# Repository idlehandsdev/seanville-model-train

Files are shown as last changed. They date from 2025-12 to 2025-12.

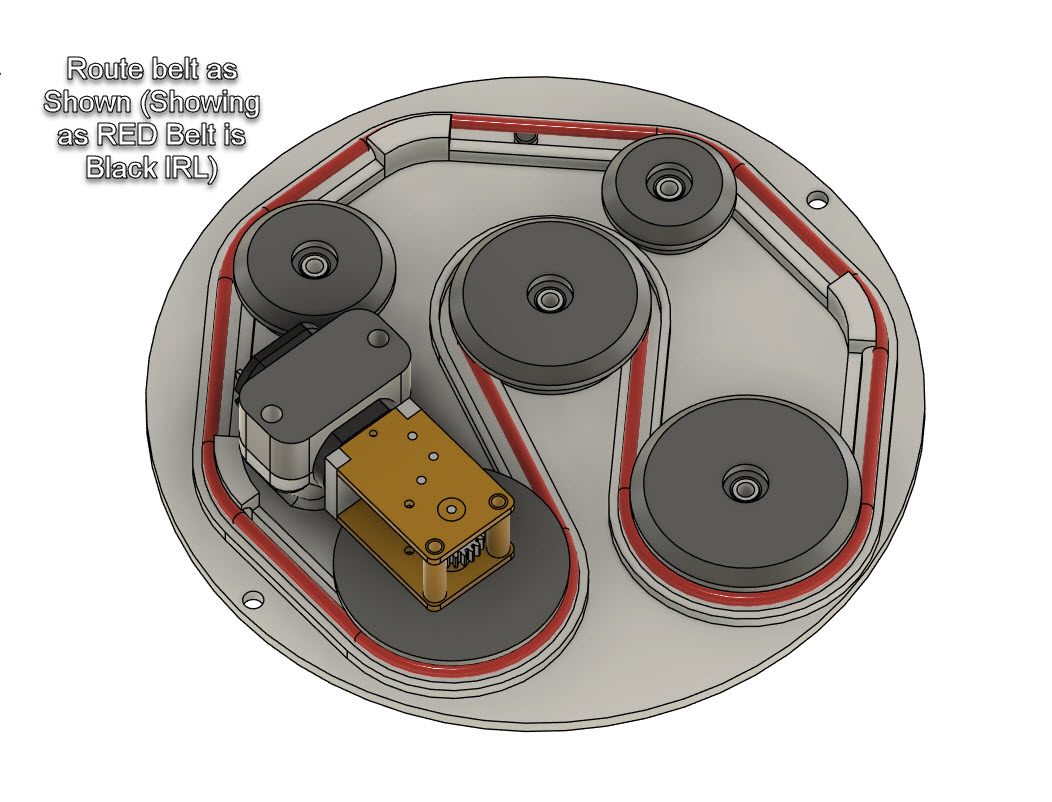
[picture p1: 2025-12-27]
instructables/belt_route.jpg

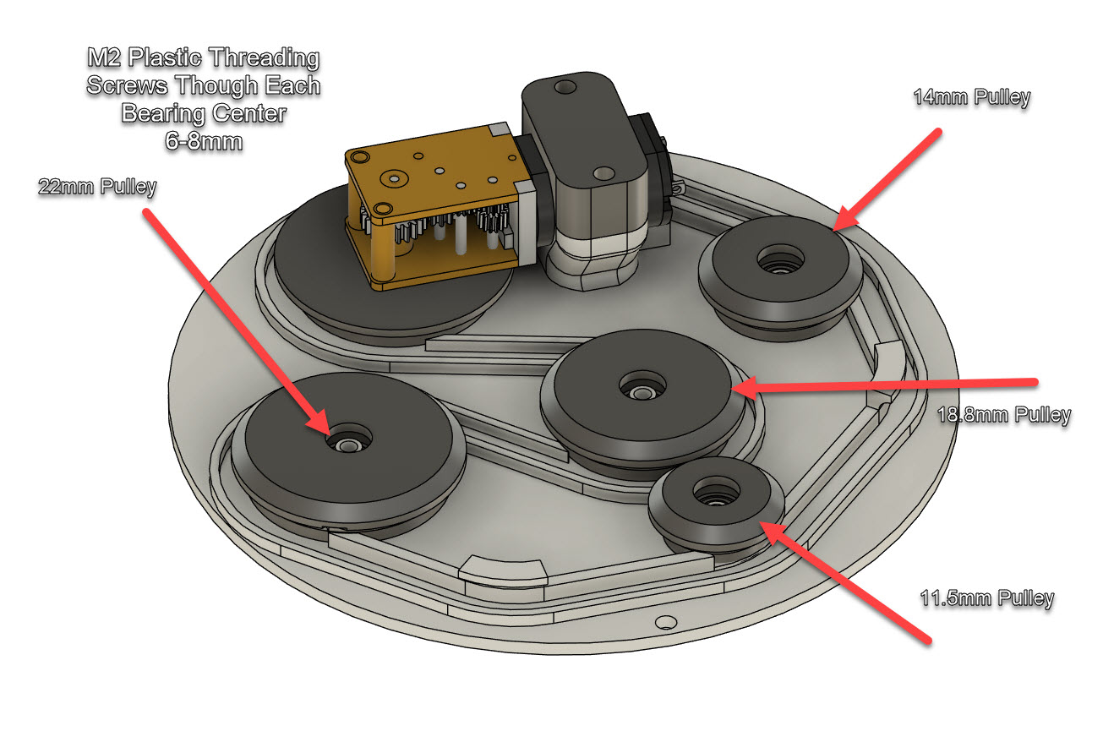
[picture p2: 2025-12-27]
instructables/pulley_screws.jpg

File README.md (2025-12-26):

# SeanVille Model Train Christmas Ornament (2025)

Watch the video (https://youtu.be/DlL3AunnM_I?si=Leu87hB8kkKHowt8)

This is my **2025 Christmas ornament project**.  
A fully self-contained **tiny model train and diorama** designed to fit entirely inside a clear Christmas ornament.

For the full context, design journey, and why some things changed along the way, **watch the video above**.

---

## Overview

The goal of this project was to build a miniature train system that could live inside a Christmas ornament while still feeling like a complete, moving system.

The original concept explored an electronically driven track, using timed control to advance the train around a PCB. As development progressed and real-world constraints showed up, the design pivoted to a **mechanically driven solution** that was simpler, more reliable, and better suited to the timeline.

The current version uses a **tiny mechanical belt system** that moves a magnet beneath the board.  
As the magnet advances, the train follows along the track above.

---

## 🚧 Work in Progress

This project is **still a work in progress**.

- The tiny magnetic track system needs further development
- Motion is currently limited and likely needs more voltage
- Additional tuning is required for smoother and more consistent movement

All of this is discussed in the video, including why the pivot happened and what still needs improvement.

---

## Current Design

- Mechanical belt-driven magnet system
- Train follows the magnet around a fixed loop
- Ornament-sized, self-contained footprint
- Designed for continuous motion and display
- Built with iteration and modularity in mind

Future revisions may revisit electronically driven concepts once reliability and timing constraints are better understood.

---

## Hardware and Parts

- **Controller:** Adafruit ESP32 Feather V2  
- **Lighting:** Adafruit wireless LED coil for flexible, wire-free lighting placement  
- **Mechanical components:** Belts, magnets, bearings, and fasteners sourced from McMaster-Carr  
- **Structure:** Custom 3D printed parts for alignment, mounting, and enclosure  

The project combines off-the-shelf hardware with printed components to keep it accessible while maintaining precision.

---

## Repository Contents

This repository contains design files, firmware, and assets related to the project.

You are encouraged to:
- Modify the design
- Improve the mechanics
- Adapt it for your own ornament, diorama, or tiny controlled environment

If you build one, or make it do something unexpected, I’d love to see it.

---

## Final Notes

Like most engineering projects, this one is shaped by compromise, iteration, and time.

What ships is never the first idea.  
It’s the version that survives.

It’s small.  
It loops.  
It runs quietly in the background.

Which feels appropriate.

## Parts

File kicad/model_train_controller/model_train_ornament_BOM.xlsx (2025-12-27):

 |  |  | xxxx xxxx xxxxx xxPCS BOM (Sample Bill of Materials)
Item # | *Designator | *Qty | Manufacturer | *Mfg Part # | Description / Value | *Package/Footprint | Type | Your Instructions / Notes
1 | A1 | 1 | Adafruit Feather ESP32 V2 |  |  |  | DNP | Feather Headers
2 | D1,D2,D3,D6 | 4 | Diodes Incorporated | 1N4148W-7-F | DIODE STANDARD 100V 150MA SOD123 | SOD-123 | SMD
3 | D4 | 1 | onsemi | MBR230LSFT1G | DIODE SCHOTTKY 30V 2A SOD123FL | SOD-123F | SMD
4 | F1,F2,F3 | 3 | Bourns Inc. | MF-USML300/6-2 | PTC RESET FUSE 6V 3A 1210 | 1210 (3225 Metric) | SMD
5 | J1 | 1 | Würth Elektronik | 691210910004 | TERM BLOCK 4P HORIZON 2.54MM PCB | 4 Position Wire to Board Terminal Block | Through Hole
6 | J2,J6 | 2 | Phoenix Contact | 1751248 | TERM BLK 2POS SIDE ENT 3.5MM PCB | 2 Position Wire to Board Terminal Block | Through Hole
7 | J3 | 1 | Same Sky (Formerly CUI Devices) | PJ-063AH | CONN PWR JACK 2X5.5MM SOLDER | Power Barrel Connector Jack 2.10mm ID (0.083"), 5.50mm OD (0.217") | Through Hole
8 | J5 | 1 | Phoenix Contact | 1725698 | TERM BLK 6P SIDE ENT 2.54MM PCB | 6 Position Wire to Board Terminal Block | DNP | Refer to Image for Populating(leave for customer)
9 | JP1 | 1 | Molex | 22285034 | CONN HEADER VERT 3POS 2.54MM | Connector Header Through Hole 3 position 0.100" | Through Hole
10 | Q1,Q2,Q3,Q5 | 4 | Alpha & Omega Semiconductor Inc. | AOSP36326C | MOSFET N-CH 30V 12A 8SOIC | 8-SOIC | SMD
11 | R1,R2,R3,R7 | 4 | YAGEO | AC0805FR-07220RL | 220 Ohms ±1% 0.125W, 1/8W Chip Resistor 0805 (2012 Metric) | 0805 (2012 Metric) | SMD
12 | R4,R5,R6,R8 | 4 | YAGEO | RC0805FR-0710KL | 10 kOhms ±1% 0.125W, 1/8W Chip Resistor | 0805 (2012 Metric) | SMD
Need a quick and accurante quote? Need an efficient production? Please read SMT Ordering Necessary Files & Info in 1 minute. Thank you very much!
Click for Instructions on How to Create a BOM (https://www.pcbway.com/blog/PCB_Assembly/How_to_Build_a_BOM__Bill_Of_Materials_.html)

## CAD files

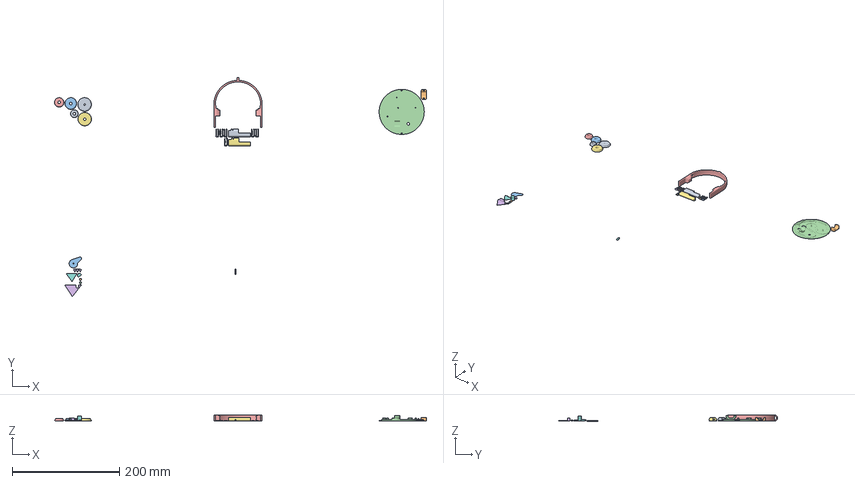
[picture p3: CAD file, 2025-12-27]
CAD/SeanVille_Model_Train_Full.3mf
692.5 x 408.0 x 12.0 mm
drive_pulley.stl
motor_clamp.stl
Lake.stl
belt_track_bearings
LED Hoop and Leg.stl
Tree Three.stl
idler_pulley_right_8mm_22.stl
Workshop.stl
Leg.stl x 2
House Big.stl
idler_pulley_center_8mm_18.stl
House Small.stl
idler_pulley_center_8mm_14.stl
Mountain_rear
Mountain_front
idler_pulley_center_8mm_11.stl
LED Clip.stl x 6
train_engine_diesel.stl

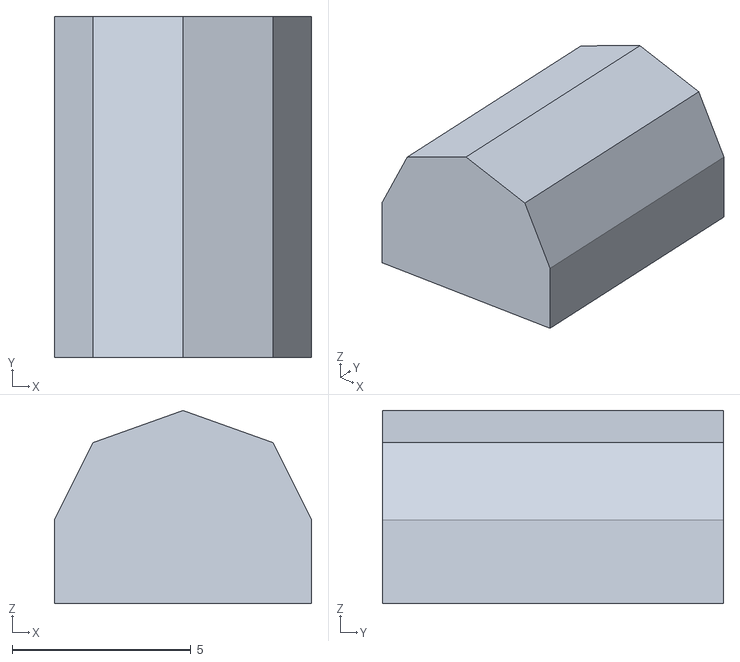
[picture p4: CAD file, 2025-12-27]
CAD/STLs/Workshop.stl
7.20 x 9.54 x 5.40

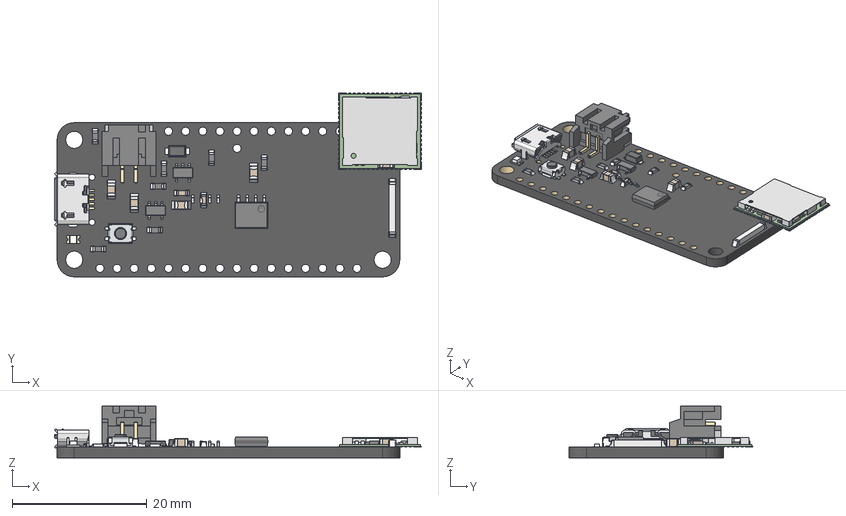
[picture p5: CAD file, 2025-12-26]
kicad/model_train_controller/project_libs/3DPackages/WICED Feather v26 v1.step
54.4 x 27.2 x 7.64 mm
board
P0
P0 solder
pin x 2
mount x 2
housing
TSOP-5 v3 x 2
cap0805_05 v2 x 5
cap0805_03 v2
cap0603_03 v3 x 2
smt_tact_button v3
package
lead x 4
lead (mirror) x 4
resistor_0603 v2 x 7
smt_led_0805 v2 x 2
SOD123W v2

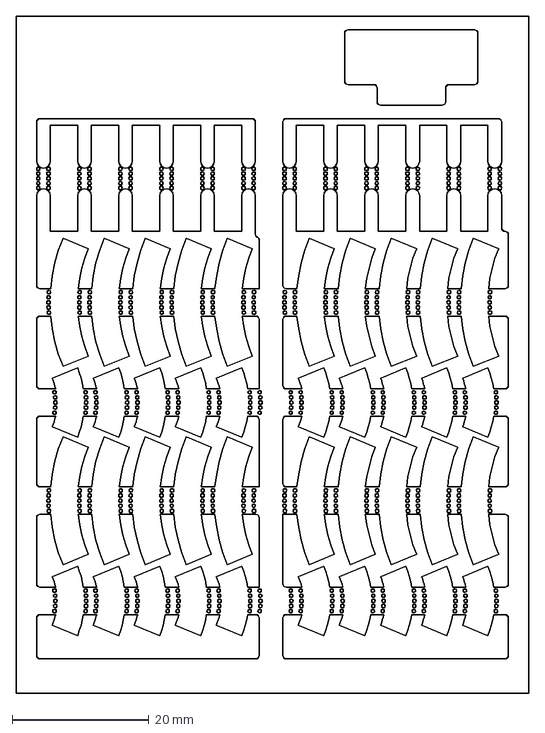
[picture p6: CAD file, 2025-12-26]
kicad/model_train_ornament/model_train_tracks_fixed.dxf
75.0 x 99.0 mm

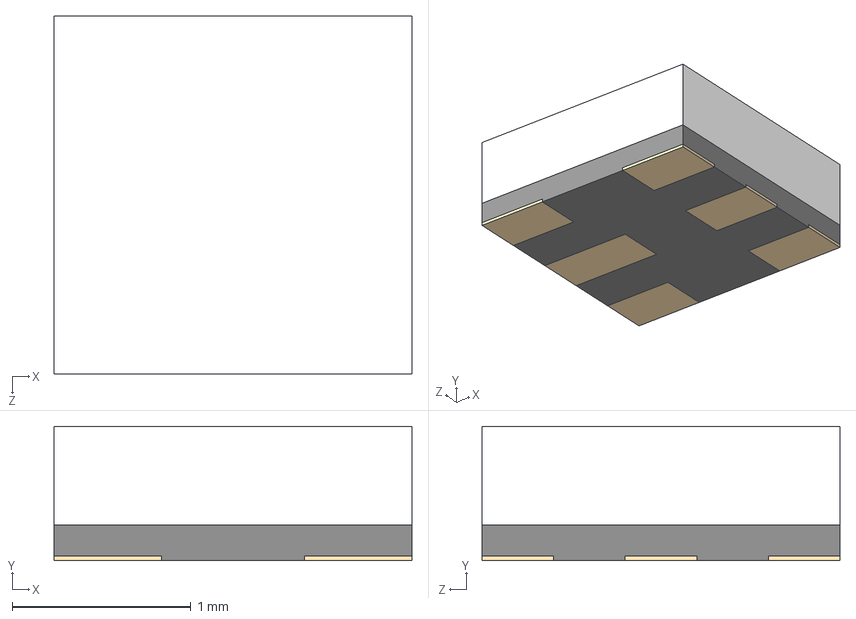
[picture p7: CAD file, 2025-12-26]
kicad/model_train_ornament/project_libs/3DPackages/BB-2020BGR-TRB.step
2.00 x 0.75 x 2.00 mm

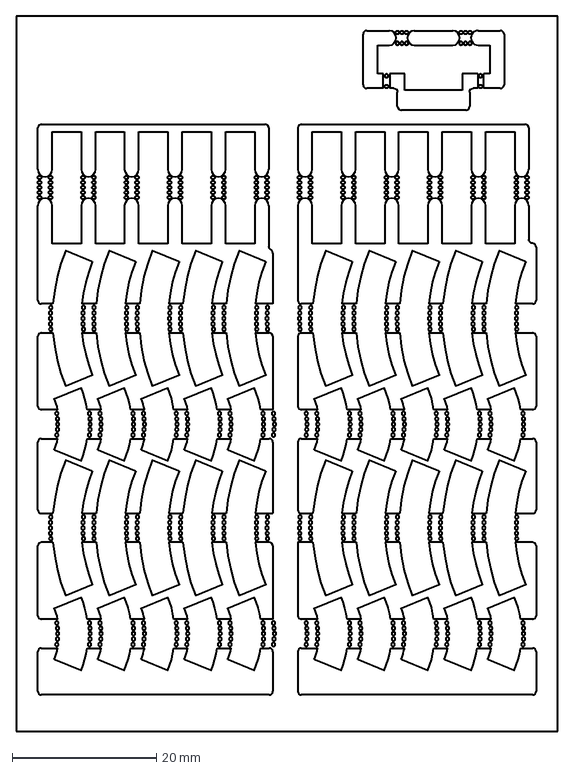
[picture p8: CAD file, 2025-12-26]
kicad/model_train_template/model_train_tracks_power.dxf
75.0 x 99.0 mm

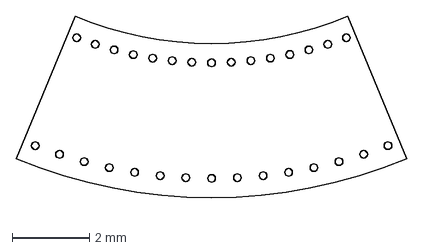
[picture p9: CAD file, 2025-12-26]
kicad/track_left_30/track_right_30_fixed.dxf
10.1 x 5.04 mm

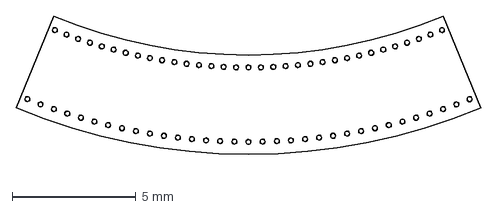
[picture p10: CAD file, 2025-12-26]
kicad/track_left_45/track_right_45.dxf
18.8 x 6.18 mm

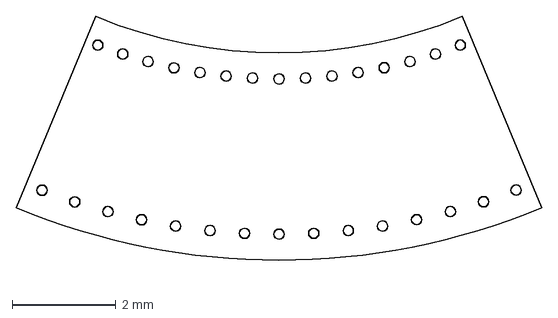
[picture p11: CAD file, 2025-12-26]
kicad/track_right_30/track_right_30.dxf
10.1 x 5.04 mm

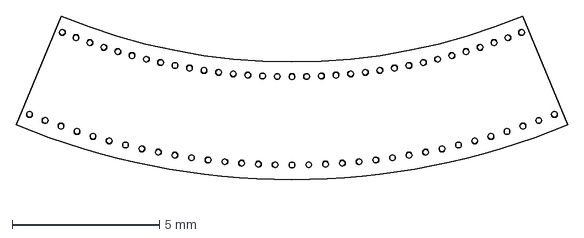
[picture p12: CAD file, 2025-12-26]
kicad/track_right_45/track_right_45_fixed.dxf
18.8 x 6.18 mm

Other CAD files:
CAD/Mountain_front.3mf
CAD/Mountain_rear.3mf
CAD/STLs/House Big.stl
CAD/STLs/House Small.stl
CAD/STLs/LED Clip.stl
CAD/STLs/LED Hoop and Leg.stl
CAD/STLs/Lake.stl
CAD/STLs/Leg.stl
CAD/STLs/Mountain Front.stl
CAD/STLs/Mountain Rear.stl
CAD/STLs/Track Base Belt Guide.stl
CAD/STLs/Tree Three.stl
CAD/STLs/drive_pulley.stl
CAD/STLs/idler_pulley_center_8mm_11.stl
CAD/STLs/idler_pulley_center_8mm_14.stl
CAD/STLs/idler_pulley_center_8mm_18.stl
CAD/STLs/idler_pulley_right_8mm_22.stl
CAD/STLs/motor_clamp.stl
CAD/STLs/train_engine_diesel.stl
CAD/belt_track_bearings.3mf
CAD/pcbway_building.3mf
kicad/model_train_ornament/model_train_ornament.step
kicad/model_train_ornament/model_train_tracks.dxf
kicad/model_train_ornament/model_train_tracks_fixed_2.dxf
kicad/model_train_single_sheet/model_train_tracks.dxf
kicad/model_train_single_sheet/model_train_tracks_fixed_2.dxf
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

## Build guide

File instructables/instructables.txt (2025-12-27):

Instructables

Parts
1 x Neodymium Magnet 1/16" Thick, 0.1" OD - https://www.mcmaster.com/5862K426/ 
1 x Neodymium Magnet 1/16" Thick, 1/16" OD - https://www.mcmaster.com/5862K137/  (get a bunch theyre small)
M2 x 10mm Plastic Threading Screws
M2 x 8mm Plastic Threading Screws
3x8x4mm Bearings x 4
1.5mm Belt ~ 10.75 length"
Adafruit Wireless LED Kit
Adafruit Feather ESP32 V2
Dotstar LED Strip (A couple Inches)
Tiny 0.6-0.8 wire (I used leads from a Capacitor)
Right Angle Geared DC Motor
Cut Dotstar LED Strip (16 LEDs)
Circuit Board from PCB - link to project

Electrical Component BOM(refer to schematics)
		
1N4148W Diotec Semiconductor x 4	
MBR230LSFT1G  x 1	
MF-USML300/12-2 x 4	
6 Pin 2.54mm Screw Terminal 1725698 Phoenix Contact x 1	
2 Pin 3.5mm Screw Terminal 1751248 Phoenix Contact x 2
4 Pin 2.54mm Screw Terminal x 1	
PJ-063AH x 1	
AOSP36326C x 4	
220R Resistor 0805 x 4
10K Resistor 0805 x 4
01x16 Pin Socket x 1
01x12 x 1

Parts to Print
Some parts require a 0.2mm nozzle

Leg LED Ring x 1
Legs x 2
Track Base Belt Guide x 1
Motor Clamp Half x 1
Idler Pulley 11mm x 1
Idler Pulley 14mm x 1
Idler Pulley 18.8mm x 1
Idler Pulley 22mm x 1
Drive Pulley x 1
LED_Clip x 6

Optional Parts to Print(as needed)
Workshop
Trees_Three
House_Big
House_Small
Lake
Mountain

Fusion360 File Viewer - https://a360.co/49g66Fe
Instructables - https://www.instructables.com/Extremely-Tiny-Model-Train-Christmas-Ornament/
PCBWay PCB Project - https://www.pcbway.com/project/shareproject/SeanVille_Tiny_Model_Train_Christmas_Ornament_Controller_4a13288b.html

Instructables Steps:

-) Watch the Video
-) Get the parts
-) Start the 3d prints, you'll be printing a lot of small stuff
-) Apply paste to PCB
-) Add small components and Reflow
-) Solder Through Hole Components - Use the Fusion360 CAD file for reference
-) Push the bearings into the 4 pulleys, and mount the pulleys on the Track Base Belt Guide Screw them down with M2 plastic threading screws
-) Push the drive pulley onto the DC Motor, add the motor clamp to hold it down, you need to align the center of the shaft with the center of the Track Base Belt Guide, align and tighten down
-) Route the Belt around the drive and idlers
-)Print Engine and Install Magnet and Wire
-) Insert the larger of the two neodymium magnets into the track and under the belt, the magnet moves by friction from the belt moving overtop of it.
-) Use doublesided tape to secure the LED strip to the underside of the hoop, apple the 3D printed clips to help the adhesive, route the LED strip wires through the hole.
-) Attach the completed circuit board to the bottom of the hoop connections, attach the legs to the circuit board as well, before installing the final leg, insert the wireless LED coil. The legs and slot will hold it in place. Connect the wires to the control board.

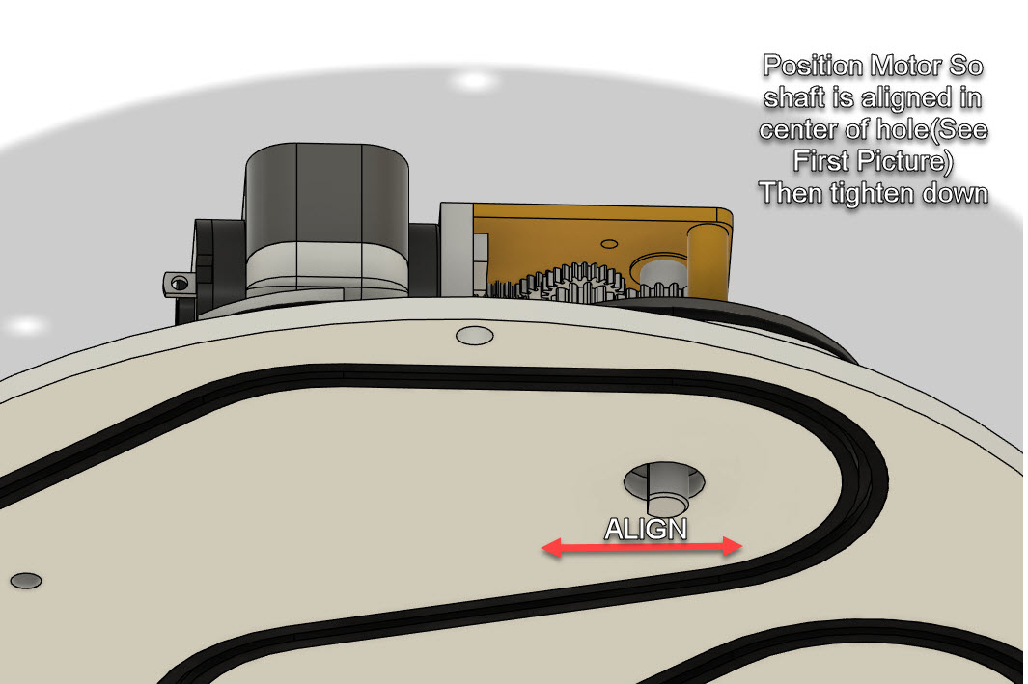
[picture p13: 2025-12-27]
instructables/motor_align.jpg

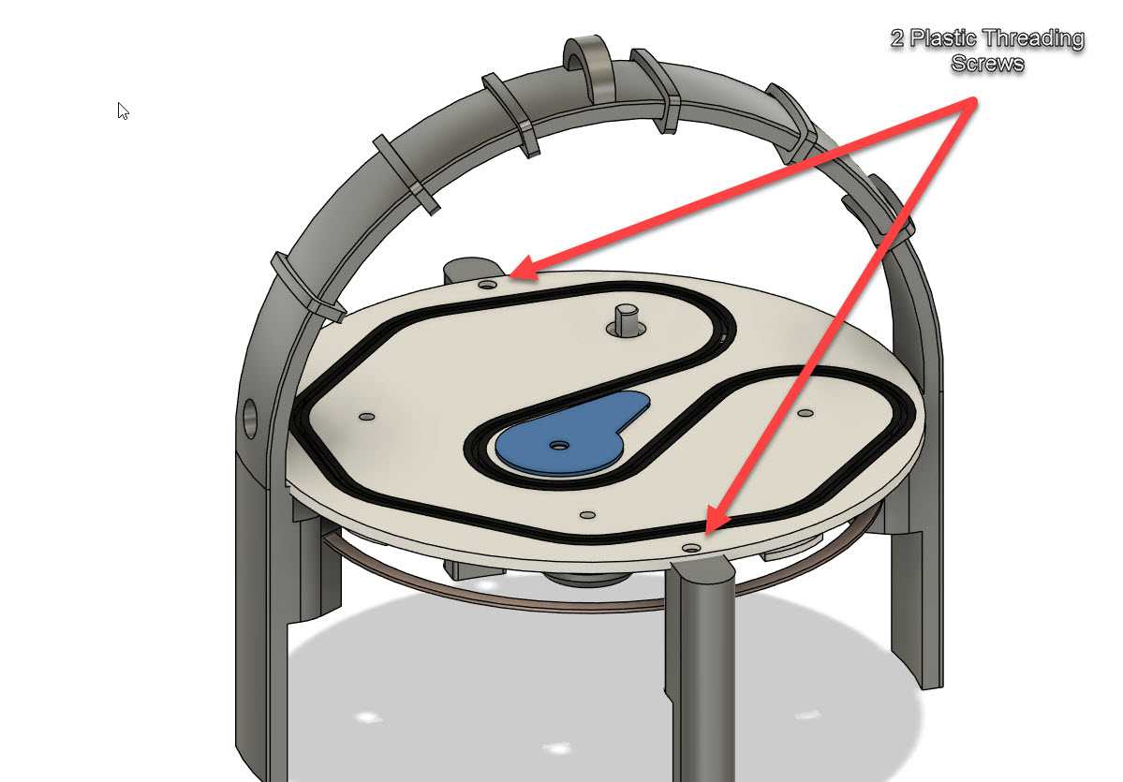
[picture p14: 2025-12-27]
instructables/base_mount.jpg

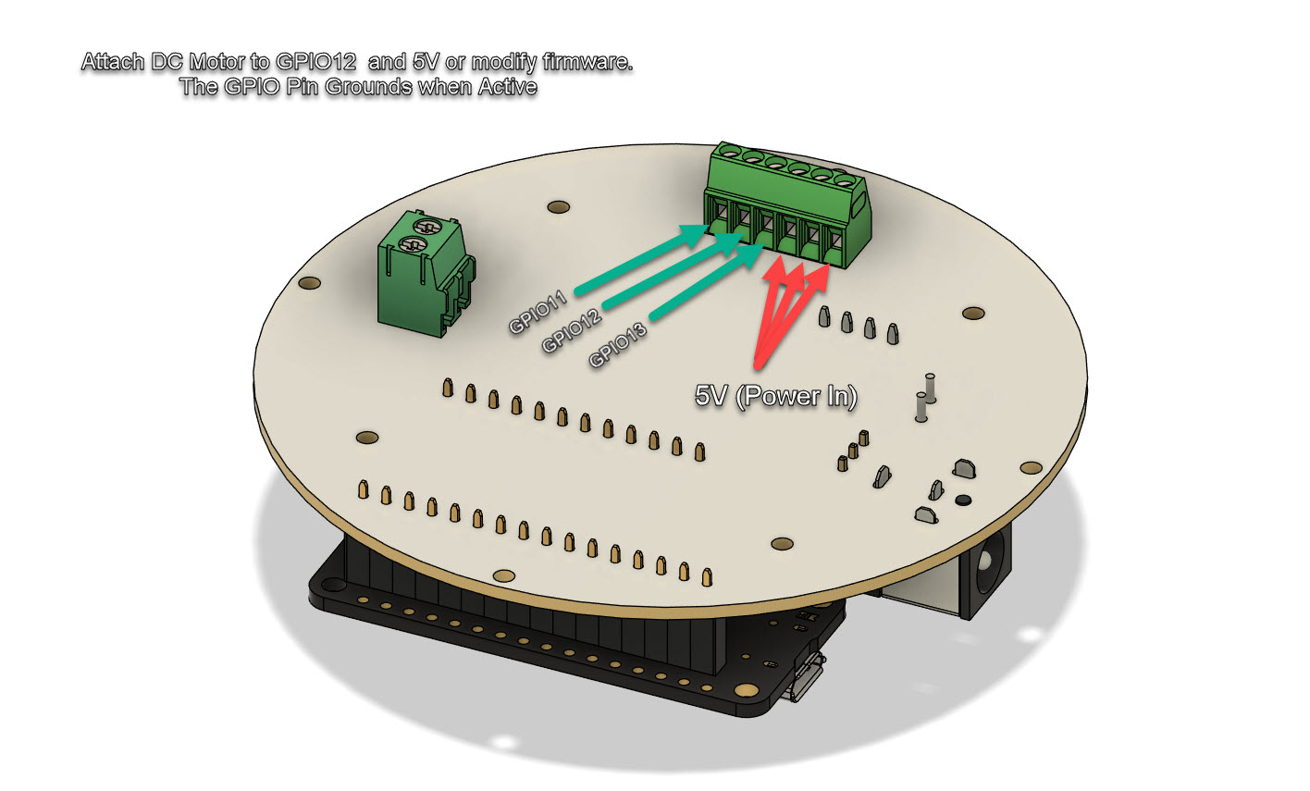
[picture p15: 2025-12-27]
instructables/motor_connection.jpg

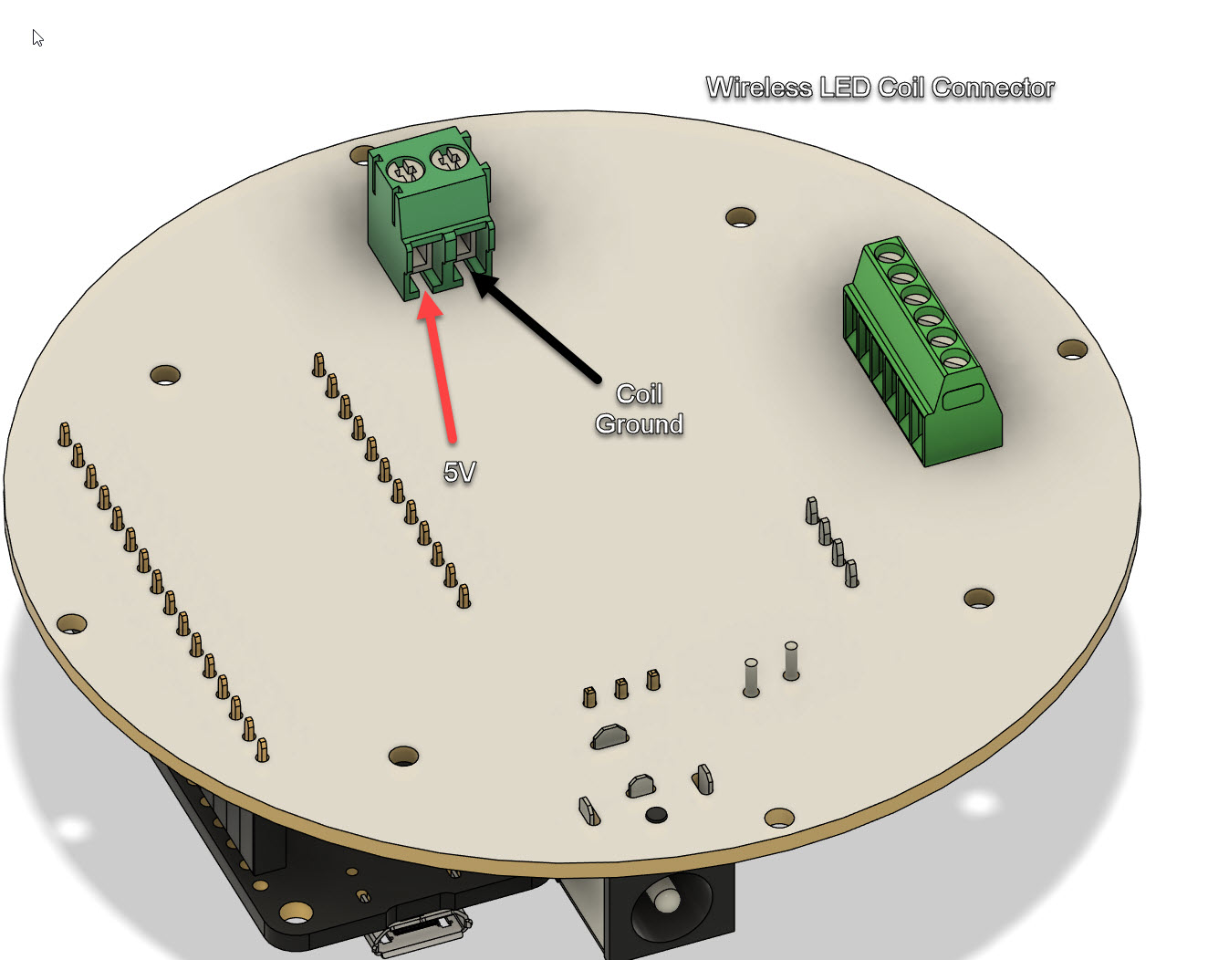
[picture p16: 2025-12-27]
instructables/wireless_coil_connections.jpg

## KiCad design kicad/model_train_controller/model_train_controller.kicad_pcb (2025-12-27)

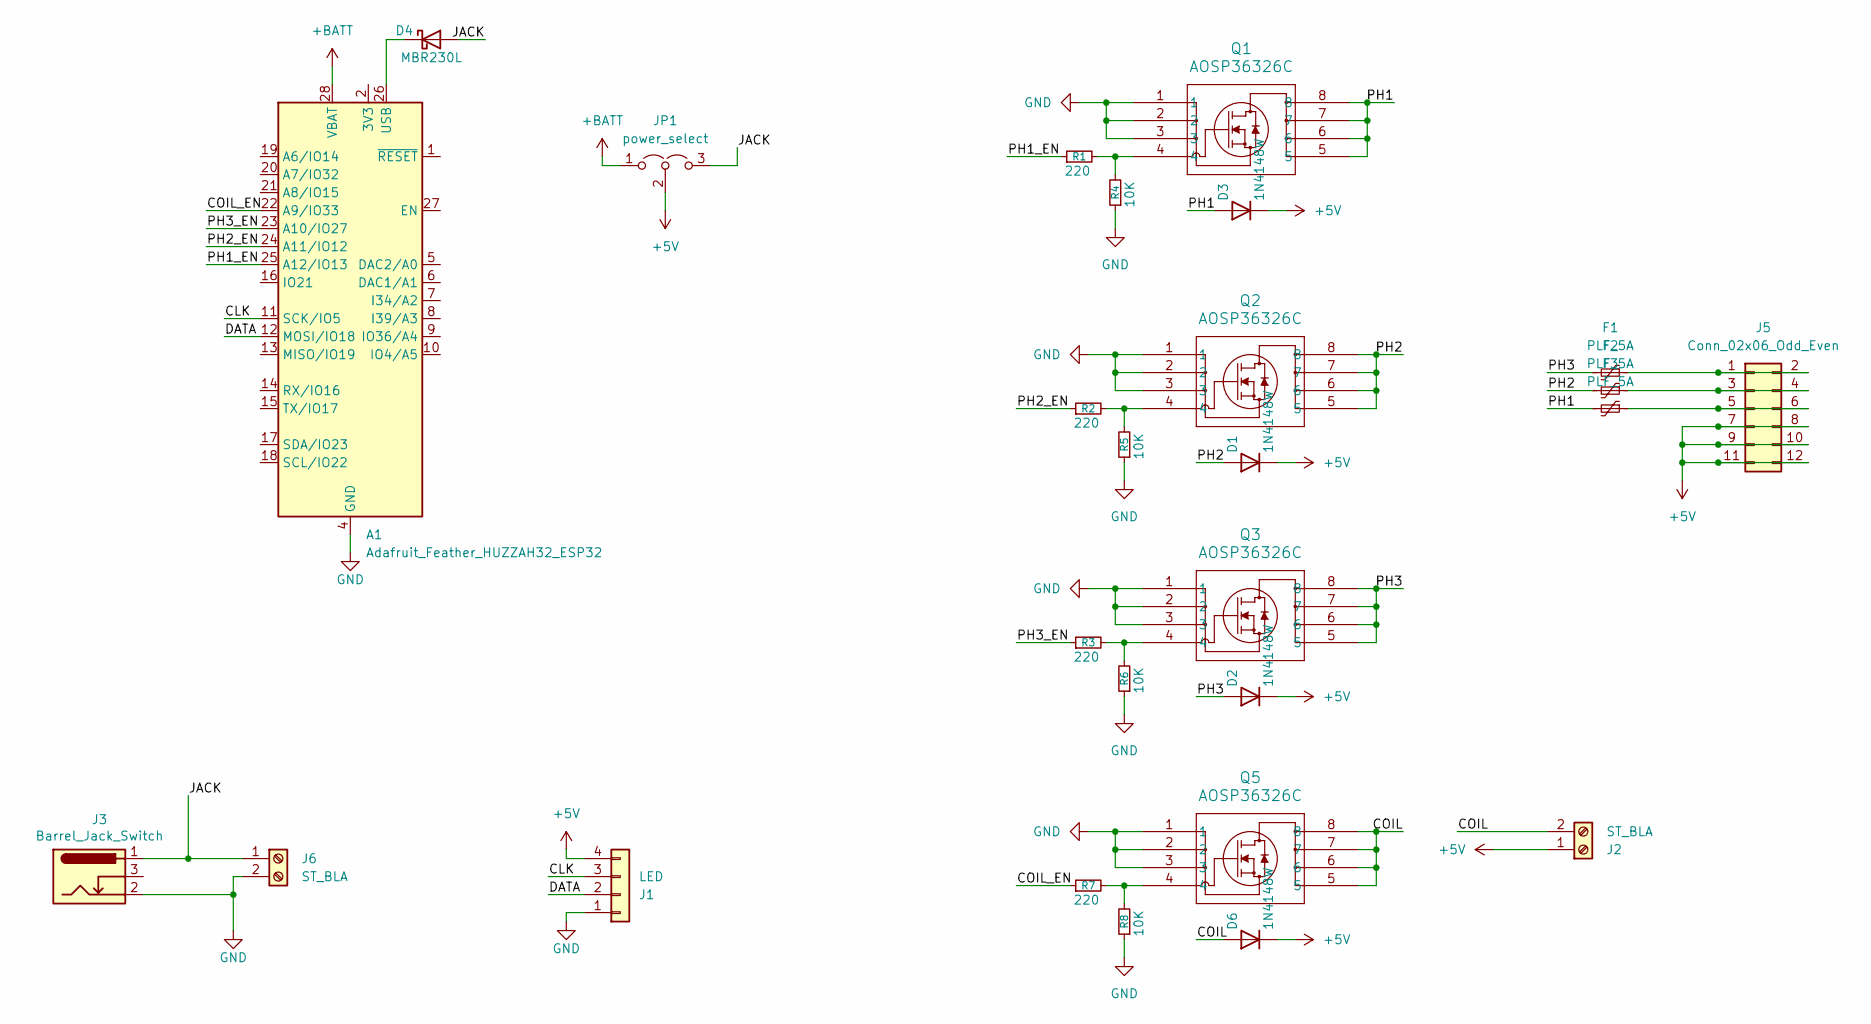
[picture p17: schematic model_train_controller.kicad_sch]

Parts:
A1: Adafruit_Feather_HUZZAH32_ESP32; Adafruit_Feather; Digikey Part No. 1528-5477-ND
D1, D2, D3, D6: 1N4148W; D_SOD-123; Digikey Part No. 1N4148W-FDITR-ND
D4: MBR230L; D_SOD-123F; Digikey Part No. MBR230LSFT1GOSCT-ND
F1, F2, F3: PLF_5A; Fuse_1210_3225Metric; Digikey Part No. 118-MF-USML300/6-2CT-ND
J1: LED; TerminalBlock_Phoenix_MPT-0,5-4-2.54_1x04_P2.54mm_Horizontal; Digikey Part No. 732-691210910004-ND
J2, J6: ST_BLA; TerminalBlock_Phoenix_PT-1,5-2-3.5-H_1x02_P3.50mm_Horizontal; Digikey Part No. 277-5719-ND
J3: Barrel_Jack_Switch; BarrelJack_CUI_PJ-063AH_Horizontal; Digikey Part No. CP-063AH-ND
J5: Conn_02x06_Odd_Even; PinHeader_2x06_P2.54mm_Vertical; Digikey Part No. 2057-PH2-12-UA-ND
JP1: power_select; PinHeader_1x03_P2.54mm_Vertical
Q1, Q2, Q3, Q5: AOSP36326C; SO8SOP-8L_AOS; Digikey Part No. 785-AOSP36326CCT-ND
R1, R2, R3, R7: 220; R_0805_2012Metric; Digikey Part No. YAG3711CT-ND
R4, R5, R6, R8: 10K; R_0805_2012Metric; Digikey Part No. 311-10.0KCRTR-ND

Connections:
+5V: D1.1 (K), D2.1 (K), D3.1 (K), D6.1 (K), J1.4, J2.1, J5.7, J5.8, J5.9, J5.10, J5.11, J5.12, JP1.2 (C)
+BATT: A1.28 (VBAT), JP1.1 (A)
/CLK: A1.11 (SCK/IO5), J1.3
/COIL: D6.2 (A), J2.2, Q5.5, Q5.6, Q5.7, Q5.8
/COIL_EN: A1.22 (A9/IO33), R7.1
/DATA: A1.12 (MOSI/IO18), J1.2
/JACK: D4.2 (A), J3.1, J6.1, JP1.3 (B)
/PH1: D3.2 (A), F3.2, Q1.5, Q1.6, Q1.7, Q1.8
/PH1_EN: A1.25 (A12/IO13), R1.1
/PH2: D1.2 (A), F2.2, Q2.5, Q2.6, Q2.7, Q2.8
/PH2_EN: A1.24 (A11/IO12), R2.1
/PH3: D2.2 (A), F1.2, Q3.5, Q3.6, Q3.7, Q3.8
/PH3_EN: A1.23 (A10/IO27), R3.1
GND: A1.4 (GND), J1.1, J3.2, J6.2, Q1.1, Q1.2, Q1.3, Q2.1, Q2.2, Q2.3, Q3.1, Q3.2, Q3.3, Q5.1, Q5.2, Q5.3, R4.1, R5.1, R6.1, R8.1
unnamed: A1.26 (USB), D4.1 (K)
unnamed: F1.1, J5.1, J5.2
unnamed: F2.1, J5.3, J5.4
unnamed: F3.1, J5.5, J5.6
unnamed: Q1.4, R1.2, R4.2
unnamed: Q2.4, R2.2, R5.2
unnamed: Q3.4, R3.2, R6.2
unnamed: Q5.4, R7.2, R8.2

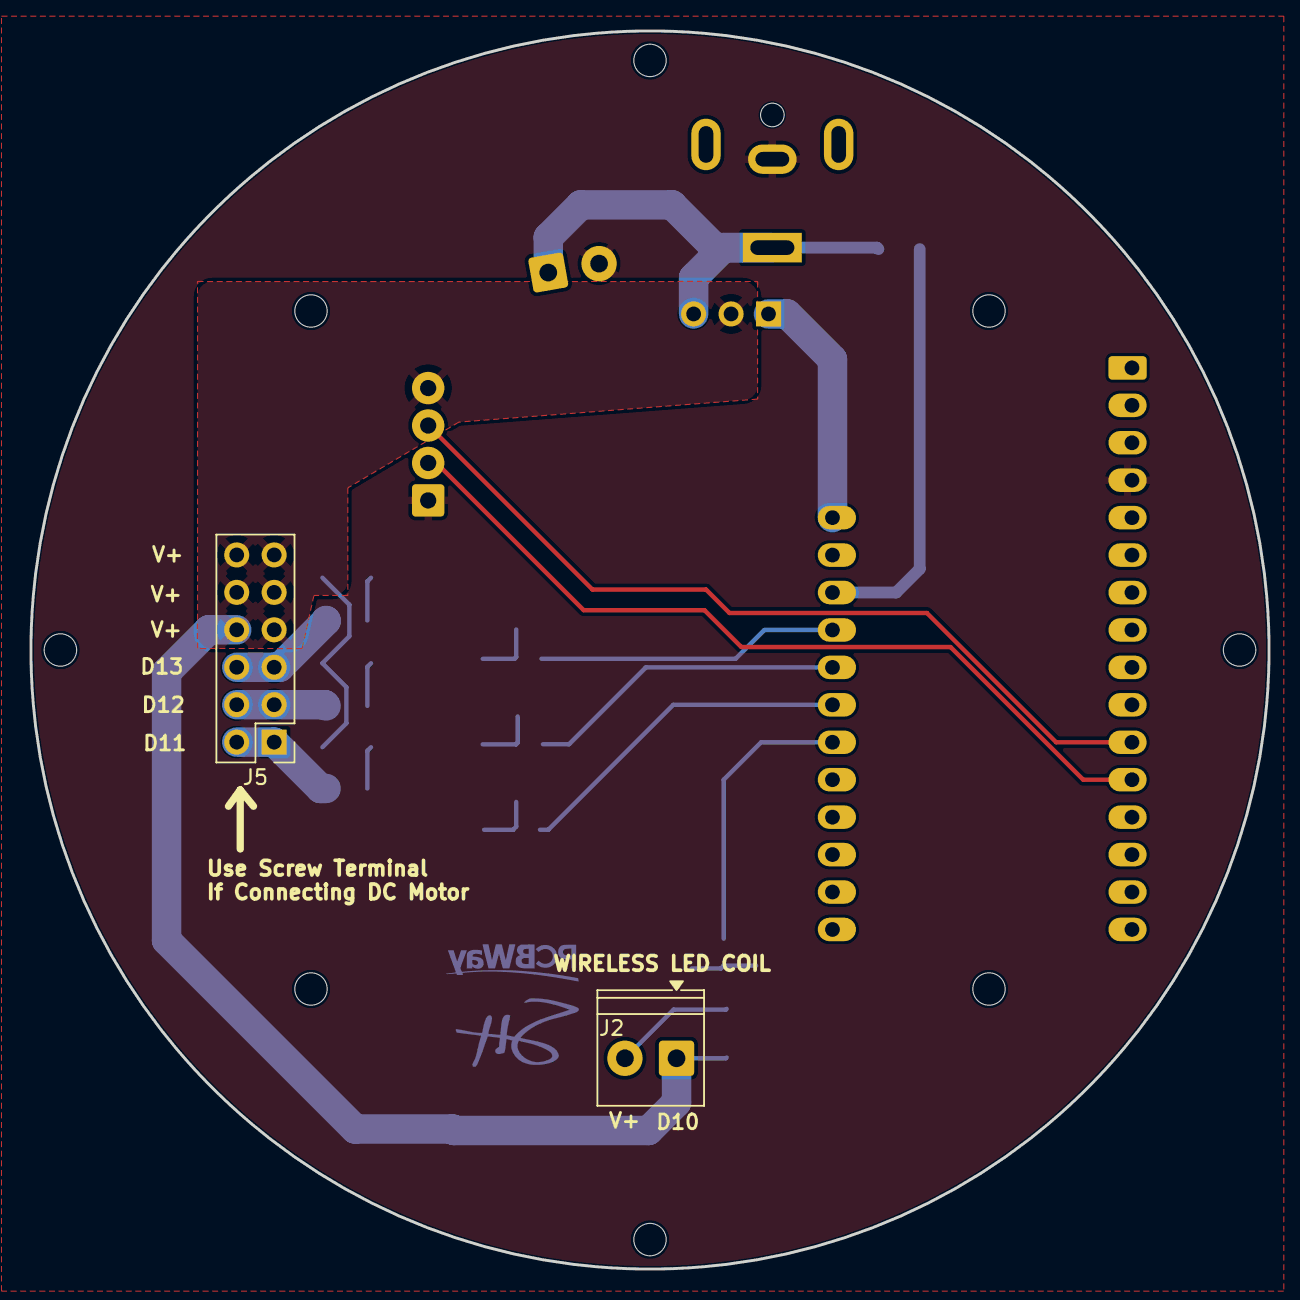
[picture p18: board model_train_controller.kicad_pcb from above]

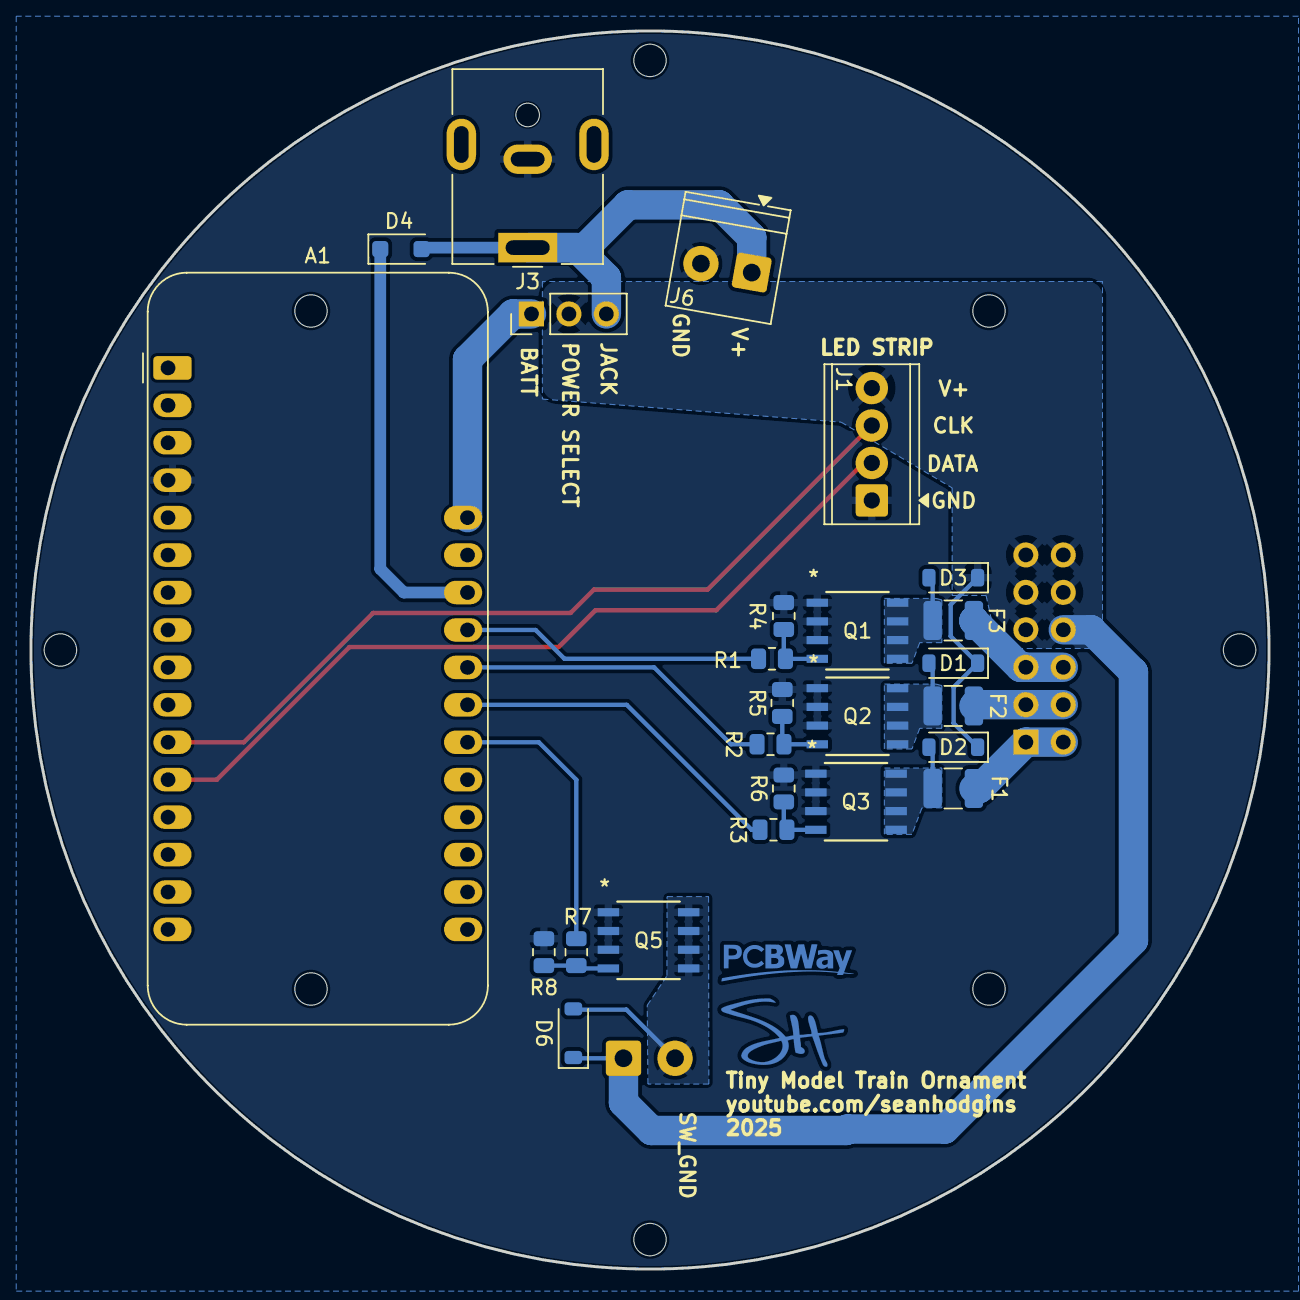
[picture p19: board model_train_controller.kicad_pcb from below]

Board: 2 copper layers, 84.0 x 84.0 mm, 27 parts (25 on the bottom side), 22 nets.

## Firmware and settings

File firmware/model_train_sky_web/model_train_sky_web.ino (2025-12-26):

/*
  ESP32-S3 Feather controller (based on your working sketch)

  Changes:
  - Added Sky Sim slider (seconds per simulated hour)
  - Added Sky Sim toggle button
  - Sky rendering is smooth between LEDs (blends two adjacent pixels)
  - Sun color shifts toward orange/red near ends (sunrise/sunset)
  - Sky is never intentionally cleared when train runs; periodic refresh keeps it "staying on"

  Pins:
  - Train DC motor: GPIO 12 (ON/OFF)
  - LED Ring: GPIO 10 (ON/OFF)
  - Sky: APA102 (16 LEDs) on MOSI/SCK
*/

#include <WiFi.h>
#include <WebServer.h>
#include <FastLED.h>
#include <time.h>

// -------- WiFi credentials --------
const char* WIFI_SSID = "YOUR_WIFI_SSID";
const char* WIFI_PASS = "YOUR_WIFI_PASSWORD";

// -------- Time / timezone --------
const char* TZ_INFO = "EST5EDT,M3.2.0/2,M11.1.0/2"; // America/Toronto rules
const char* NTP1 = "pool.ntp.org";
const char* NTP2 = "time.nist.gov";

// -------- Pins --------
static const uint8_t TRAIN_MOTOR_PIN = 12; // DC motor control (ON/OFF)
static const uint8_t LED_RING_PIN    = 10; // ON/OFF

// -------- APA102 Sky --------
static const uint8_t NUM_LEDS = 16;
CRGB leds[NUM_LEDS];

// Use Feather SPI pins (DATA=MOSI, CLK=SCK)
#ifndef MOSI
  #define MOSI 35
#endif
#ifndef SCK
  #define SCK 36
#endif
static const uint8_t APA_DATA_PIN = MOSI;
static const uint8_t APA_CLK_PIN  = SCK;

// -------- State --------
bool trainOn = false;
bool ringOn  = false;
bool skyOn   = true;

// Sky simulation
bool skySimOn = false;

// Slider controls this: real seconds per simulated hour
// (Integer slider -> float stored)
float simSecondsPerHour = 2.0f;

// Sim base time when sim is enabled
unsigned long simStartMs = 0;
int simStartHour = 12;
int simStartMinute = 0;

WebServer server(80);

// -------- Time helpers --------
bool getLocalTimeHM(int &hour24, int &minute) {
  struct tm timeinfo;
  if (!getLocalTime(&timeinfo, 50)) return false;
  hour24 = timeinfo.tm_hour;
  minute = timeinfo.tm_min;
  return true;
}

// Get sky time: real or simulated
bool getSkyTimeHM(int &hour24, int &minute) {
  if (!skySimOn) {
    // If real time temporarily fails, do not "turn off" sky; just keep last displayed
    return getLocalTimeHM(hour24, minute);
  }

  // simulated time: advance smoothly
  unsigned long now = millis();
  float elapsedSec = (now - simStartMs) / 1000.0f;

  // Guard against bad slider value
  float secPerHour = simSecondsPerHour;
  if (secPerHour < 1.0f) secPerHour = 1.0f;
  if (secPerHour > 60.0f) secPerHour = 60.0f;

  float simMinutesPerSecond = 60.0f / secPerHour;
  int deltaMinutes = (int)(elapsedSec * simMinutesPerSecond);

  int baseMinutes = simStartHour * 60 + simStartMinute;
  int totalMinutes = baseMinutes + deltaMinutes;

  totalMinutes %= (24 * 60);
  if (totalMinutes < 0) totalMinutes += (24 * 60);

  hour24 = totalMinutes / 60;
  minute = totalMinutes % 60;
  return true;
}

static inline float clamp01(float x) {
  if (x < 0.0f) return 0.0f;
  if (x > 1.0f) return 1.0f;
  return x;
}

static inline uint8_t toU8(float x) {
  if (x < 0.0f) x = 0.0f;
  if (x > 255.0f) x = 255.0f;
  return (uint8_t)(x + 0.5f);
}

// Sun color: yellow mid-day, more orange/red near ends
CRGB sunColorForT(float t01) {
  // t01 is 0..1 across day (sunrise->sunset)
  // "edge" is 1 at ends, 0 at middle
  float edge = fabsf(2.0f * t01 - 1.0f);  // 0 mid, 1 ends

  // Base "noon" color
  CRGB noon = CRGB(255, 200, 0);

  // Sunset/sunrise color (more orange/red)
  CRGB edgeCol = CRGB(255, 60, 0);

  // Blend factor: push stronger near edges
  float k = clamp01(edge * edge); // quadratic for nicer curve
  uint8_t kb = toU8(k * 255.0f);

  return blend(noon, edgeCol, kb);
}

// Moon color: bluish
CRGB moonColor() {
  return CRGB(0, 80, 255);
}

// Render sky smoothly between pixels (two adjacent LEDs blend)
void renderSkySmooth() {
  static int lastA = -999;
  static int lastB = -999;
  static uint8_t lastWa = 0;
  static uint8_t lastWb = 0;
  static bool lastIsDay = false;
  static unsigned long lastForceMs = 0;

  int h, m;
  if (!getSkyTimeHM(h, m)) {
    // If time isn't available, do nothing (do NOT clear)
    return;
  }

  const int dayStart = 6;
  const int dayEnd   = 18;
  bool isDay = (h >= dayStart && h < dayEnd);

  float hourFrac = (float)h + (float)m / 60.0f;

  // Compute t 0..1 across the active span (day or night)
  float t = 0.0f;
  if (isDay) {
    t = (hourFrac - dayStart) / (float)(dayEnd - dayStart);
  } else {
    float hf = hourFrac;
    if (hf < dayStart) hf += 24.0f; // wrap night segment
    t = (hf - dayEnd) / (float)((dayStart + 24) - dayEnd);
  }
  t = clamp01(t);

  // position in [0..NUM_LEDS-1], fractional
  float posf = t * (NUM_LEDS - 1);
  int a = (int)floorf(posf);
  int b = a + 1;
  if (b >= NUM_LEDS) b = NUM_LEDS - 1;

  float frac = posf - (float)a; // 0..1
  uint8_t wb = toU8(frac * 255.0f);
  uint8_t wa = 255 - wb;

  // Only redraw if something changed, but also force refresh periodically
  unsigned long now = millis();
  bool changed = (a != lastA) || (b != lastB) || (wa != lastWa) || (wb != lastWb) || (isDay != lastIsDay);
  bool force = (now - lastForceMs) > 2000; // force a show every 2s so it never "goes stale"

  if (!changed && !force) return;

  lastForceMs = now;
  lastA = a; lastB = b; lastWa = wa; lastWb = wb; lastIsDay = isDay;

  // Clear and set two pixels with brightness weights
  for (int i = 0; i < NUM_LEDS; i++) leds[i] = CRGB::Black;

  CRGB c = isDay ? sunColorForT(t) : moonColor();

  // Scale by weights (CRGB::nscale8_video keeps a minimum visible glow)
  CRGB ca = c; ca.nscale8_video(wa);
  CRGB cb = c; cb.nscale8_video(wb);

  leds[a] += ca;
  leds[b] += cb;

  FastLED.show();
}

void clearSky() {
  FastLED.clear(true);
}

// -------- Web UI --------
const char PAGE_INDEX[] PROGMEM = R"HTML(
<!doctype html>
<html>
<head>
  <meta name="viewport" content="width=device-width, initial-scale=1">
  <title>Train Controller</title>
  <style>
    body { font-family: sans-serif; max-width: 520px; margin: 24px auto; padding: 0 12px; }
    .card { border: 1px solid #ddd; border-radius: 10px; padding: 14px; margin: 12px 0; }
    .row { display: flex; gap: 10px; margin: 10px 0; flex-wrap: wrap; }
    button { flex: 1; padding: 14px; font-size: 16px; min-width: 150px; }
    .small { color: #666; font-size: 13px; }
    input[type="range"] { width: 100%; }
    pre { white-space: pre-wrap; }
  </style>
</head>
<body>
  <h2>Train Controller</h2>

  <div class="card">
    <div class="row">
      <button onclick="toggle('train')">Train ON/OFF</button>
      <button onclick="toggle('ring')">LEDs ON/OFF</button>
      <button onclick="toggle('sky')">Sky ON/OFF</button>
      <button onclick="toggle('skysim')">Sky Sim ON/OFF</button>
    </div>

    <div style="margin-top:12px;">
      <div>Sky Sim speed: <span id="simVal">2</span> sec / hour</div>
      <input id="sim" type="range" min="1" max="30" value="2" oninput="setSim(this.value)" />
      <div class="small">Lower = faster. 2 means 1 simulated hour every 2 seconds.</div>
    </div>
  </div>

  <div class="card">
    <button onclick="refresh()">Refresh status</button>
    <pre id="status"></pre>
  </div>

<script>
function api(path) { return fetch(path, {cache: "no-store"}).then(r => r.text()); }

function toggle(what) {
  api(`/toggle?what=${what}`).then(refresh);
}

function setSim(v) {
  document.getElementById('simVal').textContent = v;
  api(`/sim?sec=${v}`);
}

function refresh() {
  api('/status').then(t => document.getElementById('status').textContent = t);
}

refresh();
</script>
</body>
</html>
)HTML";

void handleRoot() {
  server.send(200, "text/html", PAGE_INDEX);
}

// /toggle?what=train|ring|sky|skysim
void handleToggle() {
  String what = server.arg("what");

  if (what == "train") {
    trainOn = !trainOn;
    digitalWrite(TRAIN_MOTOR_PIN, trainOn ? HIGH : LOW);

  } else if (what == "ring") {
    ringOn = !ringOn;
    digitalWrite(LED_RING_PIN, ringOn ? HIGH : LOW);

  } else if (what == "sky") {
    skyOn = !skyOn;
    if (!skyOn) clearSky();

  } else if (what == "skysim") {
    skySimOn = !skySimOn;

    // When enabling sim, seed it from real time if available
    int h, m;
    if (getLocalTimeHM(h, m)) {
      simStartHour = h;
      simStartMinute = m;
    } else {
      simStartHour = 12;
      simStartMinute = 0;
    }
    simStartMs = millis();
  }

  server.send(200, "text/plain", "OK");
}

// /sim?sec=1..30   (seconds per simulated hour)
void handleSim() {
  int sec = server.arg("sec").toInt();
  if (sec < 1) sec = 1;
  if (sec > 30) sec = 30;

  // Preserve continuity: rebase sim start so it doesn't "jump"
  if (skySimOn) {
    int h, m;
    if (getSkyTimeHM(h, m)) {
      simStartHour = h;
      simStartMinute = m;
      simStartMs = millis();
    }
  }

  simSecondsPerHour = (float)sec;
  server.send(200, "text/plain", "OK");
}

void handleStatus() {
  int h = -1, m = -1;
  bool ok = getSkyTimeHM(h, m);

  char buf[320];
  if (ok) {
    snprintf(buf, sizeof(buf),
      "sky_time: %02d:%02d%s\ntrain: %s\nleds: %s\nsky: %s\nsky_sim: %s\nsim_speed: %.0f sec / hour\n",
      h, m, skySimOn ? " (sim)" : "",
      trainOn ? "on" : "off",
      ringOn ? "on" : "off",
      skyOn ? "on" : "off",
      skySimOn ? "on" : "off",
      simSecondsPerHour
    );
  } else {
    snprintf(buf, sizeof(buf),
      "sky_time: (not synced yet)\ntrain: %s\nleds: %s\nsky: %s\nsky_sim: %s\nsim_speed: %.0f sec / hour\n",
      trainOn ? "on" : "off",
      ringOn ? "on" : "off",
      skyOn ? "on" : "off",
      skySimOn ? "on" : "off",
      simSecondsPerHour
    );
  }

  server.send(200, "text/plain", buf);
}

// -------- Setup / Loop --------
unsigned long lastSkyUpdateMs = 0;

void setup() {
  // Serial + IP printout
  Serial.begin(115200);
  delay(1200);

  // Outputs
  pinMode(TRAIN_MOTOR_PIN, OUTPUT);
  pinMode(LED_RING_PIN, OUTPUT);

  digitalWrite(TRAIN_MOTOR_PIN, LOW);
  digitalWrite(LED_RING_PIN, LOW);

  // APA102
  FastLED.addLeds<APA102, APA_DATA_PIN, APA_CLK_PIN, BGR>(leds, NUM_LEDS);
  FastLED.setBrightness(60);
  // Optional: makes low-level blends look steadier
  FastLED.setDither(false);

  clearSky();

  // WiFi connect
  Serial.print("Connecting to WiFi: ");
  Serial.println(WIFI_SSID);

  WiFi.mode(WIFI_STA);
  WiFi.begin(WIFI_SSID, WIFI_PASS);

  unsigned long t0 = millis();
  while (WiFi.status() != WL_CONNECTED && millis() - t0 < 10000) {
    delay(200);
    Serial.print(".");
  }
  Serial.println();

  if (WiFi.status() == WL_CONNECTED) {
    WiFi.setSleep(false); // reduces latency
    Serial.print("IP address: ");
    Serial.println(WiFi.localIP());
  } else {
    Serial.println("WiFi not connected yet (server still starts).");
  }

  // Time
  configTzTime(TZ_INFO, NTP1, NTP2);

  // Web
  server.on("/", handleRoot);
  server.on("/toggle", handleToggle);
  server.on("/status", handleStatus);
  server.on("/sim", handleSim);
  server.begin();

  Serial.println("Web server started.");
}

void loop() {
  server.handleClient();

  // Update sky ~20 times per second so the blending looks smooth
  // (Not heavy: only 16 LEDs)
  if (skyOn) {
    unsigned long now = millis();
    if (now - lastSkyUpdateMs > 50) {   // 50ms -> smooth motion
      lastSkyUpdateMs = now;
      renderSkySmooth();
    }
  }
}

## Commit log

2025-12-26 Initial file commit
    [BB-2020BGR-TRB.step, WICED Feather v26 v1.step, model_train.kicad_pcb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]
2025-12-27 initial CAD file commit
    [House Big.stl, House Small.stl, LED Clip.stl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]
2025-12-27 updated PBC Files and BOM
    [model_train_controller.kicad_pcb, model_train_controller.kicad_sch, model_train_ornament_BOM.xlsx]
